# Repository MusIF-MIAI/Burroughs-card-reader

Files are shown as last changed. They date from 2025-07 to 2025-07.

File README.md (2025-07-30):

# Burroughs Punched Card Reader Restoration

This project documents the restoration of a vintage **Burroughs punched card reader** by interfacing it with a **Raspberry Pi Pico** using custom circuitry and firmware. The goal is to non-destructively digitize standard IBM 80-column punch cards and make the device usable with modern systems.

---

## 🧠 Overview

The Burroughs reader uses **optical sensors** to detect holes in a punch card as it passes over a light path. Analog outputs from these sensors are conditioned by op-amps (LM324) and fed to the Raspberry Pi Pico's GPIOs.

The Pico:
- Detects card presence and movement via the **card detect** and **odometer** lines
- Samples data from the sensors at precise intervals
- Buffers and displays punch card contents
- Controls a **feeder motor** to move cards automatically
- Exposes reset and feed control via physical switches

---

## 🔌 Hardware Integration

### Inputs to the Pico

| Signal Name | GPIO | Purpose |
|---|---|---|
| D0–D12 | 0–9, 11, 12 | Punch card data bits (12 bits) |
| Odometer (Clock)| 18 | Pulses during card feed to time samples |
| Card Presence | 19 | Low = card inserted |
| Feed Switch | 26 | Toggles automatic feed |
| Reset Button | 27 | Triggers a full system reboot |

### Outputs from the Pico

| GPIO | Signal | Description |
|---|---|---|
| 20 | Feeder Pulse| Pulses the card feeder motor |
| 21 | LED (Red) | Optional status indicator |

### Analog Front-End

Each sensor LED pair is connected to a photodiode, buffered by an LM324 op-amp configured as a comparator. The output is digital (3.3V logic) and connected directly to the Pico’s GPIOs.

---

## ⚙️ Firmware Logic

The firmware is written in C using the **Pico SDK**.

### Key Concepts

- **Sampling** is triggered by a rising edge on the odometer signal.
- Sampling is delayed initially (`START_COUNT = 4` pulses) before reading the first column.
- Each column is sampled every `COLUMN_READ_COUNT = 8` odometer ticks.
- A card consists of **80 columns**, each with up to 13 punch positions.
- `BITMASK` (`0x1BFF`) masks out the relevant GPIO bits.
- If odometer pulses exceed `TOO_MANY_CLOCKS` (700), a warning is issued.

### Dual-Core Operation

- **Core 0** handles all IRQs, data sampling, and user interaction.
- **Core 1** monitors the feed switch and toggles the **feeder motor**.

### Interrupt Handlers

- **Card Detect (GPIO 19)**:
  - Falling edge → start of a card
  - Rising edge → end of card
- **Odometer (GPIO 18)**:
  - Increments `jiffies` (clock counter)
  - Triggers sampling logic
- **Reset Button (GPIO 27)**:
  - Triggers a soft reboot via the ARM AIRCR register

---

## ⌨️ Terminal Controls

- Press `' '` (spacebar) → Visual dump of card columns (`*` = punched, `_` = blank)
- Press `'a'` → Raw hexadecimal output for each column
- Press `'e'` (if enabled) → EBCDIC-decoded stream

---

## 🛠️ Restoration Steps

1. **Verified sensor outputs** and rebuilt the logic board.
2. **Designed the logic interface** to match 3.3V GPIO of the Pico.
3. **Created the firmware** with sampling and timing control.
4. **Added physical controls** for feed and reset.
5. **Implemented dual-core handling** for motor and main loop separation.
6. **Tested punch card reading** using real cards and visual/hex output.

---

## ⧉ Files

- `burroughs.kicad_sch` - Logic schematic (see image)
- `main.c` - Complete firmware code for Raspberry Pi Pico
- `README.md` - This file
- `CMakeList.txt` 

---

## 📷 Schematic Overview

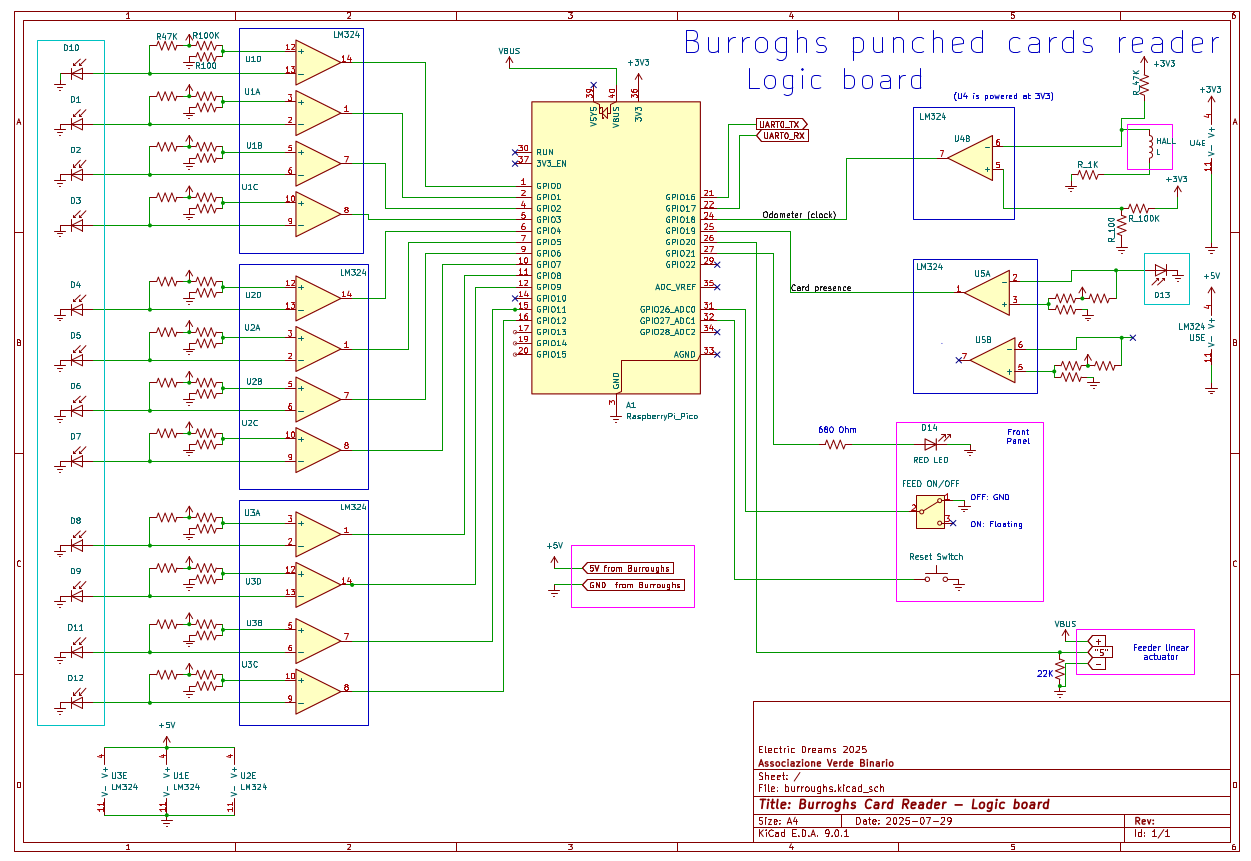
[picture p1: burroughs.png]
Burroughs Logic Schematic


---

## 🧪 Example Output

```
Card n. 1
*_*__*__...    ← Top punch row
*____*___...   ← Zone punches
**_***__*...   ← Rows 0–9
...
```

---

## 🧠 Future Improvements

- Full **EBCDIC decoding** table
- Add optional direct UART communication (instead of USB) via UART0

---

## 👥 Contributors

- Made during "Electric Dreams 2025" by Associazione Verde Binario

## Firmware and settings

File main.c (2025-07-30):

#include "pico/stdlib.h"
#include "hardware/gpio.h"
#include "hardware/timer.h"
#include "pico/multicore.h"
#include <stdio.h>
#include <string.h>

#define NUM_COLUMNS 80

#define COLUMNS 80
#define CARD_CLOCKS 684
#define TOO_MANY_CLOCKS 700

#define BITMASK (0x00001BFF)

/* Timing with the odometer. 4 cycles before start, 8 cycles per column */
#define START_COUNT 4
#define COLUMN_READ_COUNT 8

#define get_absolute_time_ms() us_to_ms(get_absolute_time())


/* GPIO input definition */
#define GPIO_ODOMETER 18
#define GPIO_CARD_DETECT 19
#define NUM_DATA_PINS 13
#define GPIO_BUTTON_RESET 27
#define GPIO_SWITCH_FEED  26
#define SWITCH_FEED_DEBOUNCE 200


/* GPIO output definition */
#define GPIO_FEEDER 20
#define GPIO_LED_RED 21

static repeating_timer_t sampler_tmr;
static volatile unsigned int col_ctr = 0;
#define MAX_CARDS 1000

static uint16_t sample[MAX_CARDS][COLUMNS];
static uint32_t card_time[MAX_CARDS];
static volatile int n_cards = 0;
static volatile uint32_t jiffies = 0;

static volatile unsigned int sample_clock_count = 0;

static volatile unsigned int card_inserted = 0;

static int feed_on = 0;

static volatile uint32_t feed_switch_last_change = 0;

#define AIRCR *(volatile uint32_t *)(0xE000ED0C)
#define AIRCR_VKEY (0x05FA << 16)
#define AIRCR_SYSRESETREQ (1 << 2)

static void arch_reboot(void)
{
    multicore_reset_core1();
    __dsb();

    AIRCR = AIRCR_SYSRESETREQ | AIRCR_VKEY;
    while(1)
        ;
}

void gpio_callback(uint gpio, uint32_t events)
{
    if (gpio == GPIO_CARD_DETECT) {
        /* FALL: card is detected */
        if ((events & GPIO_IRQ_EDGE_FALL) && (card_inserted == 0)) {
            card_time[n_cards] = jiffies;
            col_ctr = 0;
            sample_clock_count = START_COUNT;
            card_inserted = 1;
            return;
        }
        /* RISE: reading finished */
        if ((events & GPIO_IRQ_EDGE_RISE) && (card_inserted == 1)) {
            card_time[n_cards++] = jiffies;
            card_inserted = 0;
            jiffies = 0;
        }
    } else if (gpio == GPIO_ODOMETER) {
        jiffies++;
        if (!card_inserted)
            return;
        if (jiffies == TOO_MANY_CLOCKS) {
            printf("Warning: possible MISS at position %d\n", n_cards + 1); 
        }
        if (col_ctr >= COLUMNS) {
            sample_clock_count = 0;
        }
        if (sample_clock_count == 0)
            return;
        if (--sample_clock_count == 0) {
            sample[n_cards][col_ctr++] = (uint16_t)(gpio_get_all() & BITMASK);
            sample_clock_count = COLUMN_READ_COUNT;
        }
    } else if (gpio == GPIO_BUTTON_RESET) {
        arch_reboot();
    }
}

void core1_main(void)
{

    int pulse_on = 0;
    while(1) {
        uint32_t val;
        val = gpio_get(GPIO_SWITCH_FEED);
        if (!val && feed_on) {
            /* Feed off. */
            feed_on = 0;
            printf("FEED OFF\n");
        } else if (val && !feed_on) {
            /* Feed on. */
            feed_on = 1;
            printf("FEED ON\n");
        }
        if (feed_on) {
            gpio_put(GPIO_FEEDER, pulse_on);
            pulse_on = !pulse_on;
            if (pulse_on)
                sleep_ms(600);
            else
                sleep_ms(200);
        } else {
            gpio_put(GPIO_FEEDER, 0);
        }
    }
}

int main() {
    unsigned int i, j, card;
    stdio_init_all();
    sleep_ms(2000);

    // Initialize GPIOs 0 through 12 as inputs, except 10
    for (i = 0; i < NUM_DATA_PINS; ++i) {
        if (i == 10)
            continue;
        gpio_init(i);
        gpio_set_dir(i, GPIO_IN);
        gpio_pull_up(i);  // Enable pull-up
    }

    /* Odometer: input, pulled down */
    gpio_init(GPIO_ODOMETER);
    gpio_set_dir(GPIO_ODOMETER, GPIO_IN);
    gpio_pull_down(GPIO_ODOMETER);

    /* Card detect: input, pulled down */
    gpio_init(GPIO_CARD_DETECT);
    gpio_set_dir(GPIO_CARD_DETECT, GPIO_IN);
    gpio_pull_down(GPIO_CARD_DETECT);

    /* Feeder: on/off button to control the flow */
    gpio_init(GPIO_SWITCH_FEED);
    gpio_set_dir(GPIO_SWITCH_FEED, GPIO_IN);
    gpio_pull_up(GPIO_SWITCH_FEED);

    /* Reset: momentary button to reset the sample counter, pulled up */
    gpio_init(GPIO_BUTTON_RESET);
    gpio_set_dir(GPIO_BUTTON_RESET, GPIO_IN);
    gpio_pull_up(GPIO_BUTTON_RESET);

    /* Outputs: feeder and led */
    gpio_init(GPIO_FEEDER);
    gpio_set_dir(GPIO_FEEDER, GPIO_OUT);
    gpio_put(GPIO_FEEDER, 0);

    gpio_init(GPIO_LED_RED);
    gpio_set_dir(GPIO_LED_RED, GPIO_OUT);
    gpio_put(GPIO_LED_RED, 0);

    /* Set up interrupts */
    gpio_set_irq_enabled_with_callback(GPIO_ODOMETER, GPIO_IRQ_EDGE_RISE, true, &gpio_callback);
    gpio_set_irq_enabled_with_callback(GPIO_CARD_DETECT, GPIO_IRQ_EDGE_RISE|GPIO_IRQ_EDGE_FALL, true, &gpio_callback);
    gpio_set_irq_enabled_with_callback(GPIO_BUTTON_RESET, GPIO_IRQ_EDGE_FALL, true, &gpio_callback);

    multicore_launch_core1(core1_main);
    printf("System up and running.\n");

    while (1) {
        char c;
        uint32_t val; 
        // Wait for card to be inserted (all pins 0)
        while (!card_inserted) {
            c = getchar_timeout_us(0);
            if (c == ' ') {
                for (card = 0; card < n_cards; card++) {
                    printf("Card n. %d\n", card + 1);
                    for (i = 0; i < COLUMNS; i++) {
                        printf((sample[card][i] & (1u << 12u))?"*":"_");
                    }
                    printf("\n");
                    for (i = 0; i < COLUMNS; i++) {
                        printf((sample[card][i] & (1u << 11u))?"*":"_");
                    }
                    printf("\n");
                    for (j = 0; j < 10; j++) {
                        for (i = 0; i < COLUMNS; i++) {
                            printf((sample[card][i] & (1u << j))?"*":"_");
                        }
                        printf("\n");
                    }
                    printf("\n\n");
                }
                printf("Total cards: %d\n", n_cards);
                printf("\n\n");
            }
            if (c == 'a' || c == 'A') {
                for (card = 0; card < n_cards; card++) {
                    printf("Card n. %d\n", card + 1);
                    for (i = 0; i < COLUMNS; i++) {
                        printf("%04X ", sample[card][i]);
                    }
                    printf("\n");
                }
                printf("Total cards: %d\n", n_cards);
                printf("\n\n");
            }
        }
        asm volatile("wfi");
    }
    return 0;
}

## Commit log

2025-07-27 Tested board reading (time based)
2025-07-28 Testing integration of card-sense on pin 13 via GPIO 19
2025-07-29 Relay control, control panel, leds etc.
2025-07-30 Added kicad schematics
    [burroughs.kicad_pcb, burroughs.kicad_sch]
